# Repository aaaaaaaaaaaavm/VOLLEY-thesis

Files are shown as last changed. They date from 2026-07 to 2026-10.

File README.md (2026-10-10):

# VOLLEY Gen5 — final-year thesis and review

### A controlled electromagnetic CubeSat deployer configuration, evaluated by computation

This repository is the **standalone academic record** for VOLLEY Gen5. For the 10 October review, start with [how to present the old numbers and known errors](university/final_review_2026_10_10/READ_THIS_FIRST.md), then download the [offline presentation and evidence pack](university/final_review_2026_10_10/TOMORROW_PRESENTATION_PACK.zip). The repository holds the technical [manuscript](source/VOLLEY_IEEE_Conference.pdf), editable [source](source/paper.tex), model scripts and outputs, CAD, validation sheets, assumptions, defects, and the college [final-review presentation pack](university/final_review_2026_10_10/README.md). A professor can follow a slide claim to a result file and method without opening another repository.

> **Scope, October 2026:** Gen5 is the fixed computational configuration for academic review, with documented model cases and open verification items. It yields a modeled orbital benefit, a failed installed-mass criterion, and a failed side-fed CAD fit. The final academic freeze has not been declared; nothing has been built, fired, measured, qualified or flown. Gen6 is the proposed first mission-derived instrumented prototype programme; 1 km/s-class release is separate long-range research. It has no selected architecture or achieved speed.

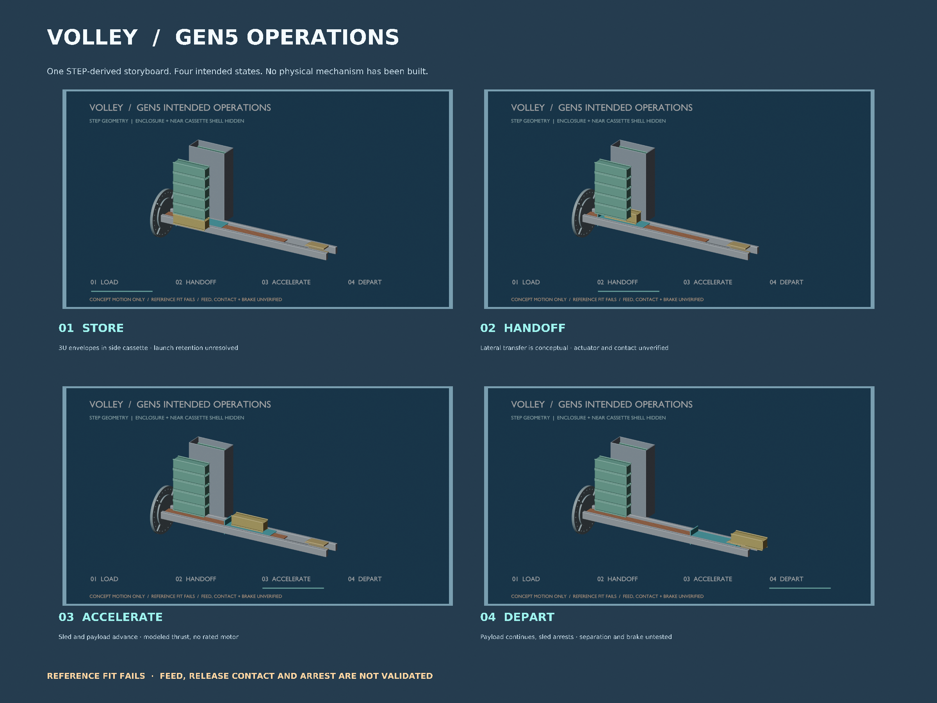
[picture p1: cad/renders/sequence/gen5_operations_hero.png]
Four-stage STEP-derived Blender storyboard of intended Gen5 storage, handoff, acceleration and departure


*The intended order of operations, shown with local FreeCAD-linked STEP solids. The enclosure and near cassette shell are hidden. The evaluated reference assembly has a known track/cassette clash; feed, contact and brake motion are unverified. [Watch the eight-second sequence](cad/renders/sequence/gen5_intended_sequence.mp4) · [view animation provenance](cad/renders/sequence/README.md) · [inspect the static geometry audit](cad/renders/step_review/README.md). This is a model visualization, not hardware.*

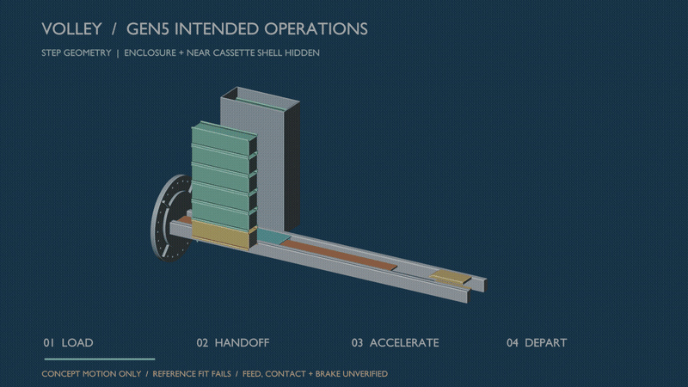
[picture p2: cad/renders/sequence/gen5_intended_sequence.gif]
Gen5 intended-operations concept animation, not a tested mechanism


> **Finding for the examiner:** the finite 3-D analytic force screen gives **12.448 m/s under ideal phase**, challenging the earlier **16.029 m/s** periodic-model shot. A separate 2-D FEM screen finds **1.082 kJ** ideal work. A conditional finite-force bank calculation gives **2.099 kJ** gross for the assumed full winding. None establishes a selected motor rating. [3-D analytic screen](validation/P118_gen5_finite_force_map.md) · [2-D FEM](validation/P119_gen5_finite_force_fem2d.md) · [coupled bank case](validation/P120_gen5_finite_coupled_shot.md) · [affected-claim disposition](docs/GEN5_2026_10_09_FINDING_DISPOSITION.md).

> **New cross-check and sensitivity:** an [independent depth-resolved 3-D surface-charge formulation](validation/P121_gen5_finite_force_surface3d.md) returns **1.042 kJ ideal work**, agreeing with the analytic finite-force screen under shared geometry and material assumptions. [Illustrative geometry cases](validation/P122_gen5_finite_force_sensitivity.md) reduce ideal work to **0.907 kJ at a 14 mm face gap** versus 12 mm nominal. These are computational screens, not measured tolerances or an accepted speed rating.

> **Updated finding for the examiner, 10 October 2026:** [P123](validation/P123_gen5_one_event_mass_screen.md) calculates a one-release installed-mass trade with the same assumed host and payload. The ideal finite-force Gen5 case saves **1.866 kg** of fuel if both options carry 10 kg, but its modeled device is **54.562 kg** heavier. With fuel hypothetically resized for only one event, Gen5 remains **52.717 kg** heavier on the device-plus-fuel proxy. Achieving parity at this ideal speed requires about **52.630 kg** less device dry mass. [Code](analysis/gen5_one_event_mass_screen.py) · [result JSON](analysis/results/gen5_one_event_mass_screen.json). This does not close a twelve-shot mission or validate a motor. The manuscript, report and review deck now include the limited P123 result and the later P125 source-power failure, P126 assumed R1 tolerance and P127 arrest bound.

> **Additional viva bound:** even if an ideal release removed the host preburn entirely, the same one-event comparison allows at most **74.659 kg** of Gen5 device against the current 126.562 kg model. [Recompute it locally](analysis/gen5_architecture_bounds.py) · [read the unselected H1 hypothesis](docs/GEN5_H1_INTEGRATED_DEPLOYER_HYPOTHESIS.md). The manuscript and report include the bound; H1 remains unselected.

> **New examiner requirements screen, P124:** [orbit and stroke calculations](validation/P124_precision_delivery_design_space.md) show how a declared 450 km orbital-state tolerance becomes an ideal tangential velocity margin. They also give about **39,220 g** for 1 km/s over Gen5's 1.3 m stroke with a 4 kg payload. This is a kinematic screen, not a motor rating or qualified load. The report, manuscript and slide 23 now include the result. [Code](analysis/precision_delivery_design_space.py) · [result](analysis/results/precision_delivery_design_space.json).

The [P127 release/arrest bounds](validation/P127_gen5_release_arrest_bounds.md) find 731.8 J of sled kinetic energy at the **ideal** finite-force speed. Over the provisional 210 mm brake corridor, stopping it needs at least 37.6 g mean sled deceleration; the first-order host reaction and net recoil are also bounded. Eddy-current peak force, payload contact, host attitude and repeated-shot thermal behavior remain unsolved.

> **P125 drive feasibility screen:** A quasi-steady, three-phase voltage/current model uses the finite Gen5 force map and the historical **unselected** winding and 96 V source. The reference surrogate reaches 12.448 m/s; halving the current limit gives 8.802 m/s and halving the initial source voltage gives 10.794 m/s. A single string at the older 116–185 mΩ commercial ESR bound **fails the source-power equation before release**; ideal parallel-string branches complete while multiplying source cells and mass. These are conditional model outputs, **not a rated release speed or selected drive**. [Method and limits](validation/P125_gen5_voltage_limited_screen.md) · [source](analysis/gen5_voltage_limited_screen.py) · [result](analysis/results/gen5_voltage_limited_screen.json).

The [prototype-to-flight decision gates](docs/GEN6_PROTOTYPE_TO_FLIGHT_ROADMAP.md) make the proposed Gen6 first article and later engineering, qualification and flight stages reviewable. None is an achieved Gen6 milestone.

Ideal speed, stroke and payload-load screen

P123 one-event installed device and fuel comparison

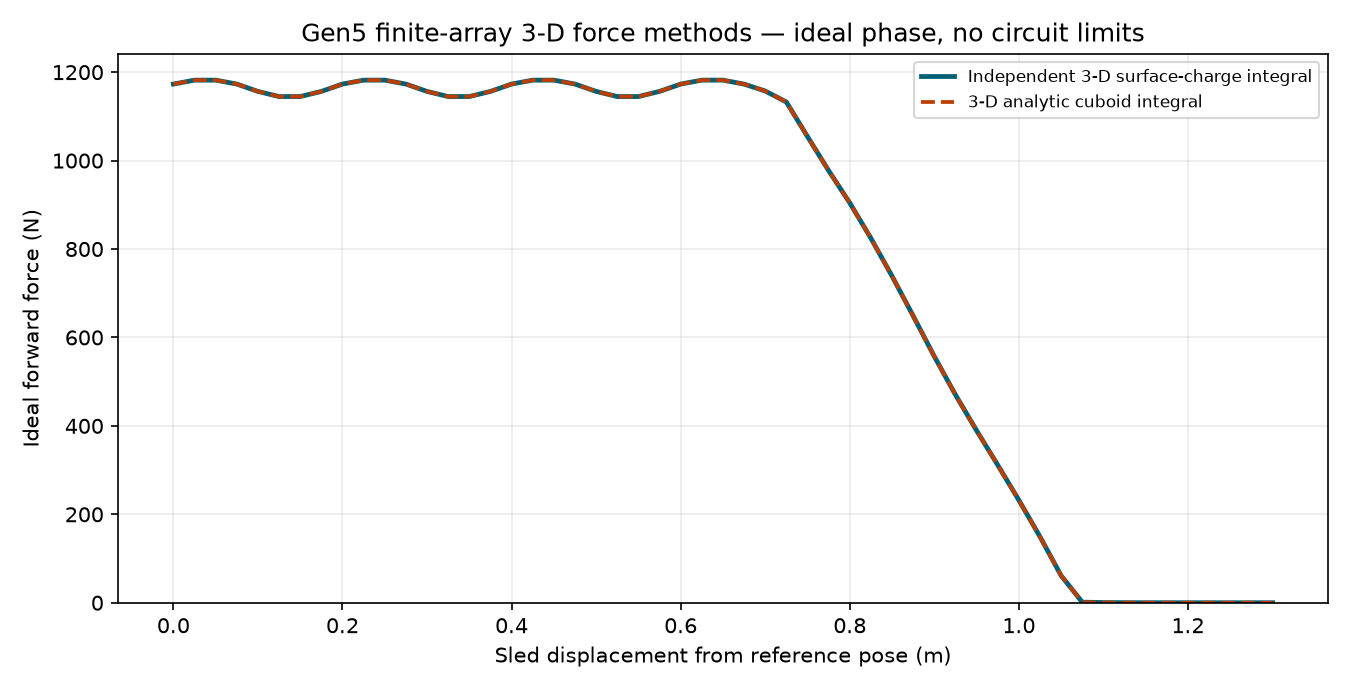
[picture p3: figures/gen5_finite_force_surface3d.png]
Independent depth-resolved ideal-force check
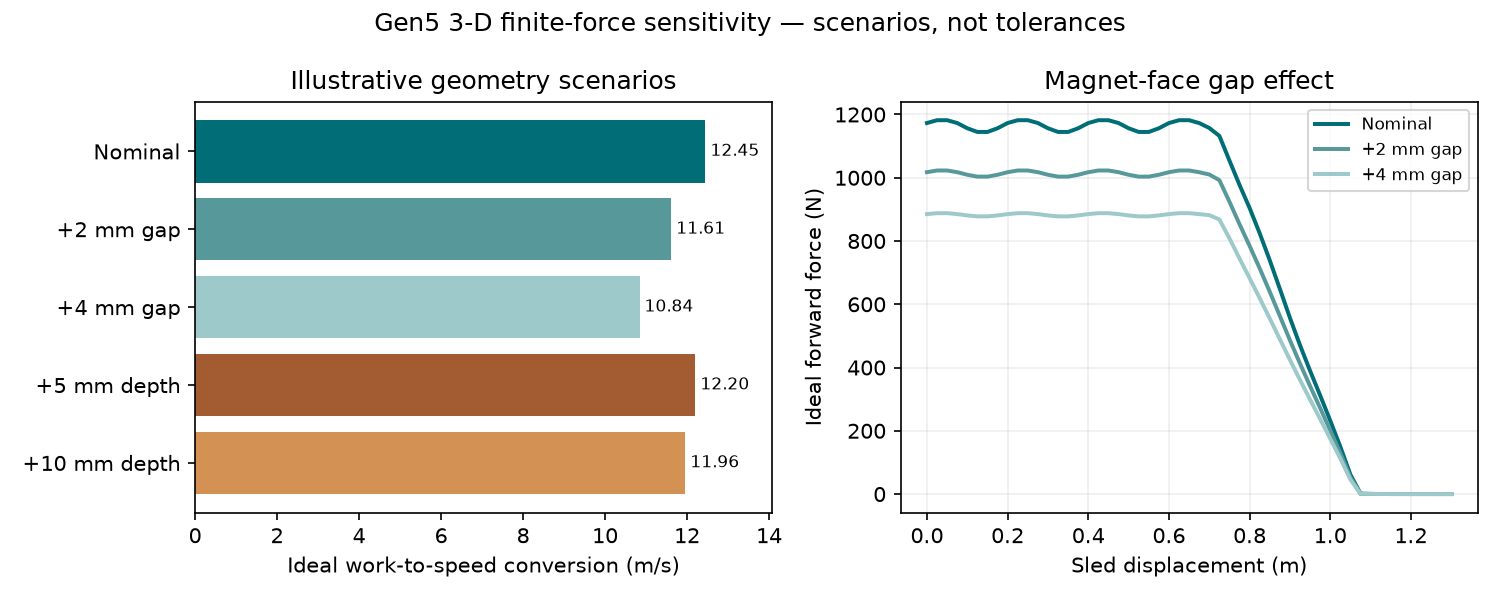
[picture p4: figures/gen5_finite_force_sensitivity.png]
Deterministic magnet gap and depth scenarios


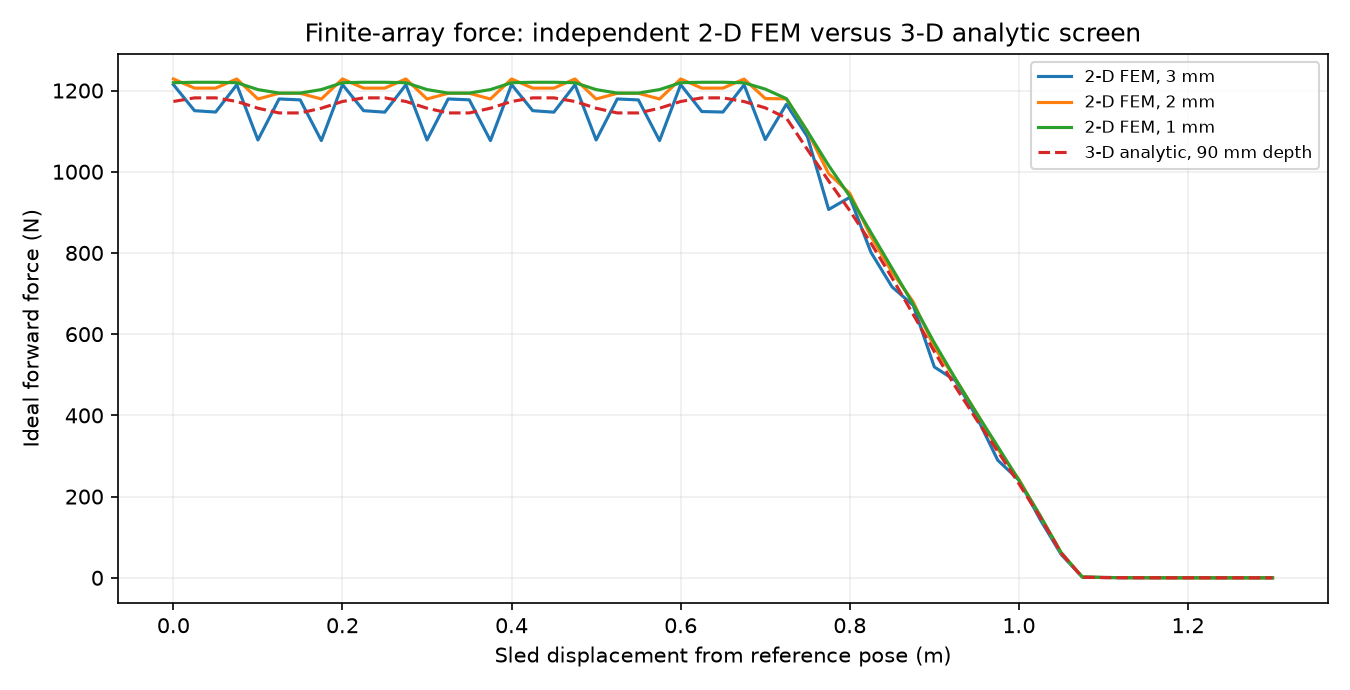
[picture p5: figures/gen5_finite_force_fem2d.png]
Finite 2-D FEM force comparison
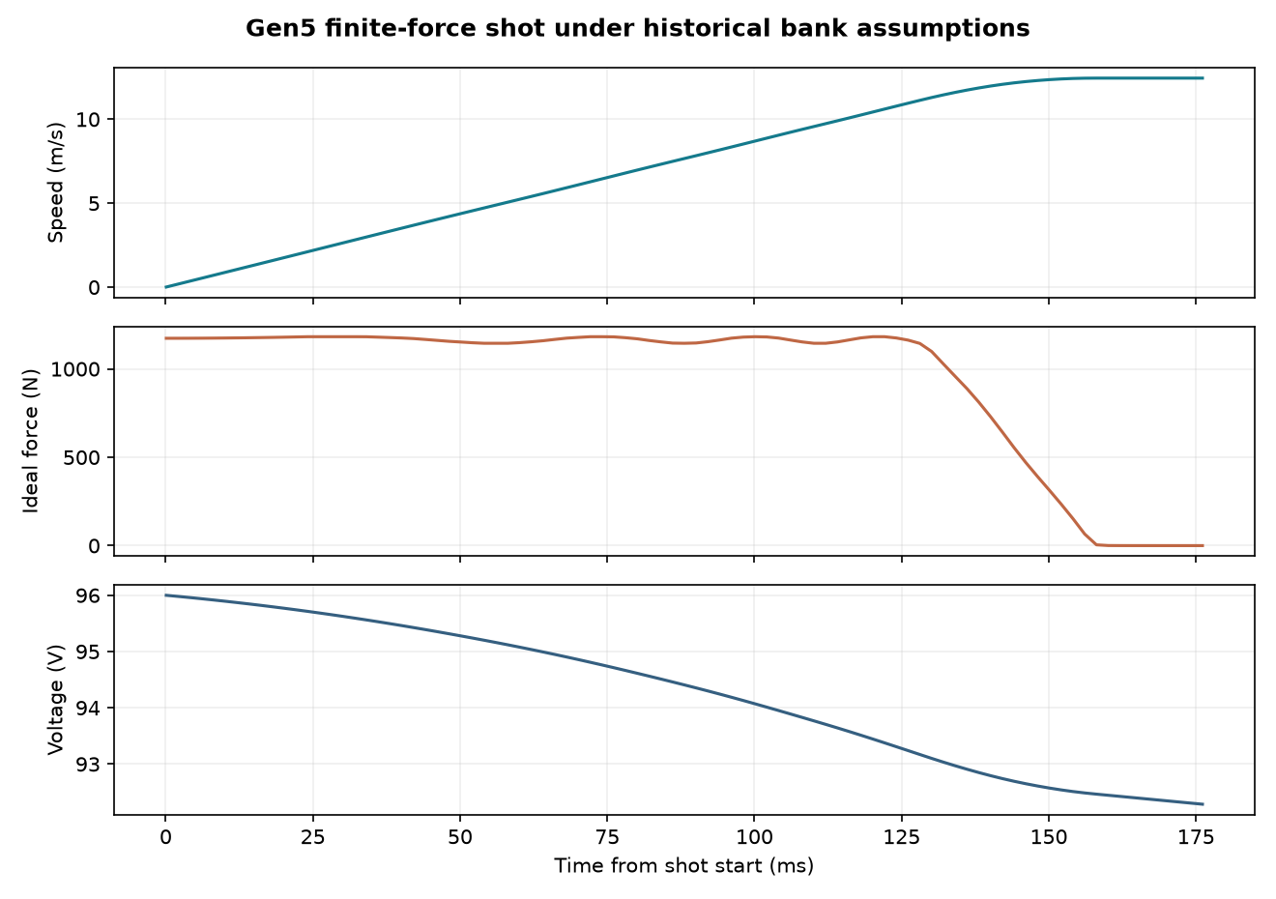
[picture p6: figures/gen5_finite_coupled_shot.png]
Assumed finite-force bank trajectories


*The FEM omits magnet-depth end effects and the coupled shot retains assumed bank, converter and ideal phase. The [matched reference](docs/MATCHED_MISSION_REFERENCE.md) uses assumed host and dispenser properties; none of its spring or Gen5 twelve-shot cases closes.*

<p align="center">VOLLEY mission concept and Gen5 model chain</p>

*Model and mission architecture. A host and provider interface have not been selected.*

## Bring this to the final review

| Deliverable | Open it | Evidence route |
|:--|:--|:--|
| **26-slide college presentation** | [PDF](university/final_review_2026_10_10/VOLLEY_Final_Review_2026-10-10.pdf) · [editable PPTX](university/final_review_2026_10_10/VOLLEY_Final_Review_2026-10-10.pptx) | [Slide-by-slide claim map](university/final_review_2026_10_10/CLAIM_EVIDENCE_MAP.md) |
| **Panel handbook** | [PDF](university/final_review_2026_10_10/PANEL_HANDBOOK.pdf) · [Markdown](university/final_review_2026_10_10/PANEL_HANDBOOK.md) | Detailed explanations and figures |
| **Presenter reference** | [PDF](university/final_review_2026_10_10/PRESENTER_REFERENCE.pdf) · [Markdown](university/final_review_2026_10_10/PRESENTER_REFERENCE.md) | Slide notes and viva responses |
| **Final-year project report** | [PDF](university/GEN5_FINAL_YEAR_REPORT.pdf) · [Markdown](university/GEN5_FINAL_YEAR_REPORT.md) | Chaptered academic review draft; college-specific format remains to be applied |
| **Technical manuscript** | [PDF](source/VOLLEY_IEEE_Conference.pdf) · [LaTeX](source/paper.tex) | [Local evidence guide](ACADEMIC_EVIDENCE.md) |
| **Engineering review reports** | [Computational PDF](reports/GEN5_COMPUTATIONAL_REVIEW.pdf) · [FreeCAD/CAD PDF](cad/GEN5_CAD_REVIEW.pdf) | [Orbit check](validation/P115_rated_orbit_cartesian.md) · [Assembly check](validation/P116_gen5_assembly_packaging.md) |

The presentation pack credits **Adityavardhan Mishra and Pratham Chawla**, with guide **Vikas Gulia**. The existing technical manuscript names Adityavardhan Mishra; the review pack does not retroactively change its authorship. [Remaining CAD and IEEE work](IEEE_AND_CAD_REMAINING_WORK.md) · [IEEE prior-art update](IEEE_PRIOR_ART_UPDATE_2026-10-09.md) · [Manuscript claim audit](CLAIM_CORRECTIONS_2026-10-09.md) · [Pack instructions](university/final_review_2026_10_10/README.md) · [Review-pack checksums](university/final_review_2026_10_10/CHECKSUMS.sha256) · [Academic artifact checksums](ARTIFACT_MANIFEST.sha256).

To rebuild the chaptered report from this repository, run `pandoc university/GEN5_FINAL_YEAR_REPORT.md -o university/GEN5_FINAL_YEAR_REPORT.pdf --pdf-engine=xelatex --resource-path=university`. Its source includes the page format and font settings. The college supplied a final-review rubric and example slides, but no mandatory report template; the PDF is an academic review draft awaiting that format and final authorship confirmation.

**Market context for the viva:** [audited customer and spacecraft fit](MARKET_AND_CUSTOMER_FIT.md). It checks the relevant Drive market report and independent business-case review against primary industry sources and the Gen5 result. Candidate buyers and satellite classes are hypotheses, not endorsed customers or qualified payloads.

## The result to defend

Gen5 is one specified system: a release station 1.5 m from the breech on 1.8 m structural longerons, with a 1.3 m powered stroke, ironless double-sided Halbach linear motor, reusable permanent-magnet sled, pulse store, eddy-current arrest and two conceptual cassettes for twelve ordinary 3U CubeSats. The release load and mechanical/electrical compatibility of any actual CubeSat remain unqualified.

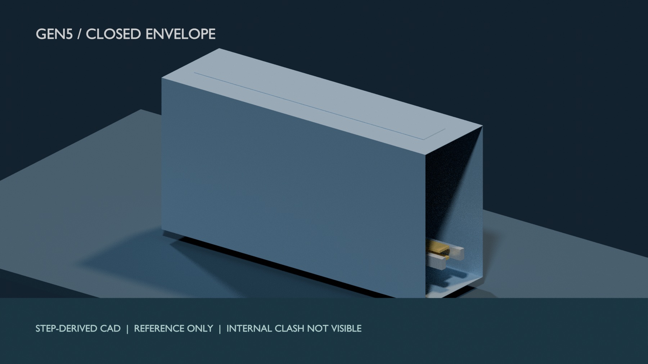
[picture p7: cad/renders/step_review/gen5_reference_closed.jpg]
Gen5 outer reference envelope from STEP; internal clash concealed
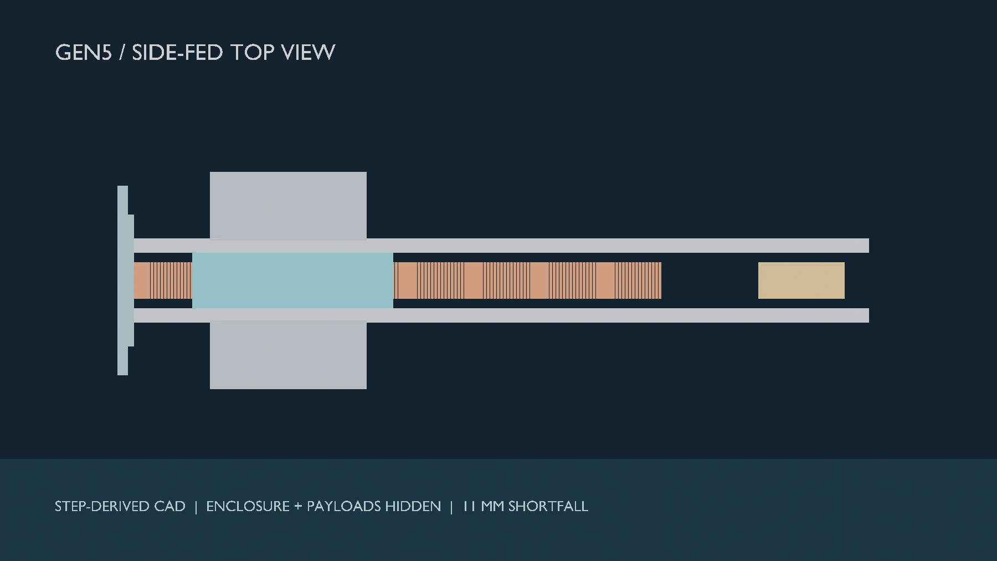
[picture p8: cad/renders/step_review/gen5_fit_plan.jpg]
Gen5 reference side-fed track and cassettes from STEP; enclosure and payloads hidden


*Gen5 CAD models. These depict the evaluated geometry; they are not built articles or manufacturing drawings. [Inspect local CAD](cad/).*

| Study question | Modeled Gen5 answer | Examiner's qualification |
|:--|--:|:--|
| Historical rated 3U departure | **16.029 m/s at 10.07 g** | Periodic model challenged by finite geometry; not a measured command range or payload qualification |
| Energy draw | **2.78 kJ gross per shot** | Circuit model at the rated point |
| Exit-speed dispersion | **0.0274 m/s (3σ)** | Simulation under assumed sensor uncertainty |
| Dry / loaded design mass | **126.6 / 174.6 kg** | Modeled rollup with historical Gen3 sled volumes and assumed components, not a complete installed host mass |
| Mass per carried 3U | **10.547 kg** | **Fails** the approximately 2 kg/satellite economic screen |
| Incumbent canister parity | **1.758×** a roughly 6 kg/3U canister | **Fails** the separate ±15% parity band |
| One modeled 450 km orbit case | **28.8 km** semi-major-axis rise; **1.60×** lifetime | Conditional atmosphere and orbit assumptions; current lifetime point lacks an independent rerun |
| Current rated two-body cross-check | **28.800775 km** immediate axis rise | Independent Cartesian propagation; lifetime, host and delivery excluded |
| Side-fed reference assembly fit | **11 mm shortfall** | FreeCAD and CadQuery exact solids collide by 32,915 mm³ per cassette |

[Frozen numerical baseline](appendix/BASELINE.md) · [Claim provenance](appendix/PROVENANCE.md) · [Study limits and viva questions](ACADEMIC_EVIDENCE.md) · [Defect register](appendix/OPEN_PROBLEMS.md)

<p align="center">Gen5 mass per 3U against the canister and economic screens Historical periodic-model shot energy accounting</p>

*These review charts are generated by the local [plot script](tools/plot_gen5_decision.py) from [mass](analysis/results/mass_properties.json) and historical [shot](analysis/results/motor_results.json) outputs. The canister value is approximate; [P117](validation/P117_rated_energy_mass_audit.md) reconciles the old 124.488 J compact-output remainder to model assumptions. This does not verify installed power hardware.*

<p align="center">Rated two-body orbit check Gen5 reference assembly interference</p>

*The CAD finding is deliberately retained in the [native FreeCAD document](cad/native/Gen5_Review.FCStd) and [assembly STEP](cad/step/gen5/VOLLEY_Review_Assembly_FreeCAD_Gen5.step). The orbit check supports immediate two-body geometry only. [Methods and exact files](reports/GEN5_COMPUTATIONAL_REVIEW.pdf).*

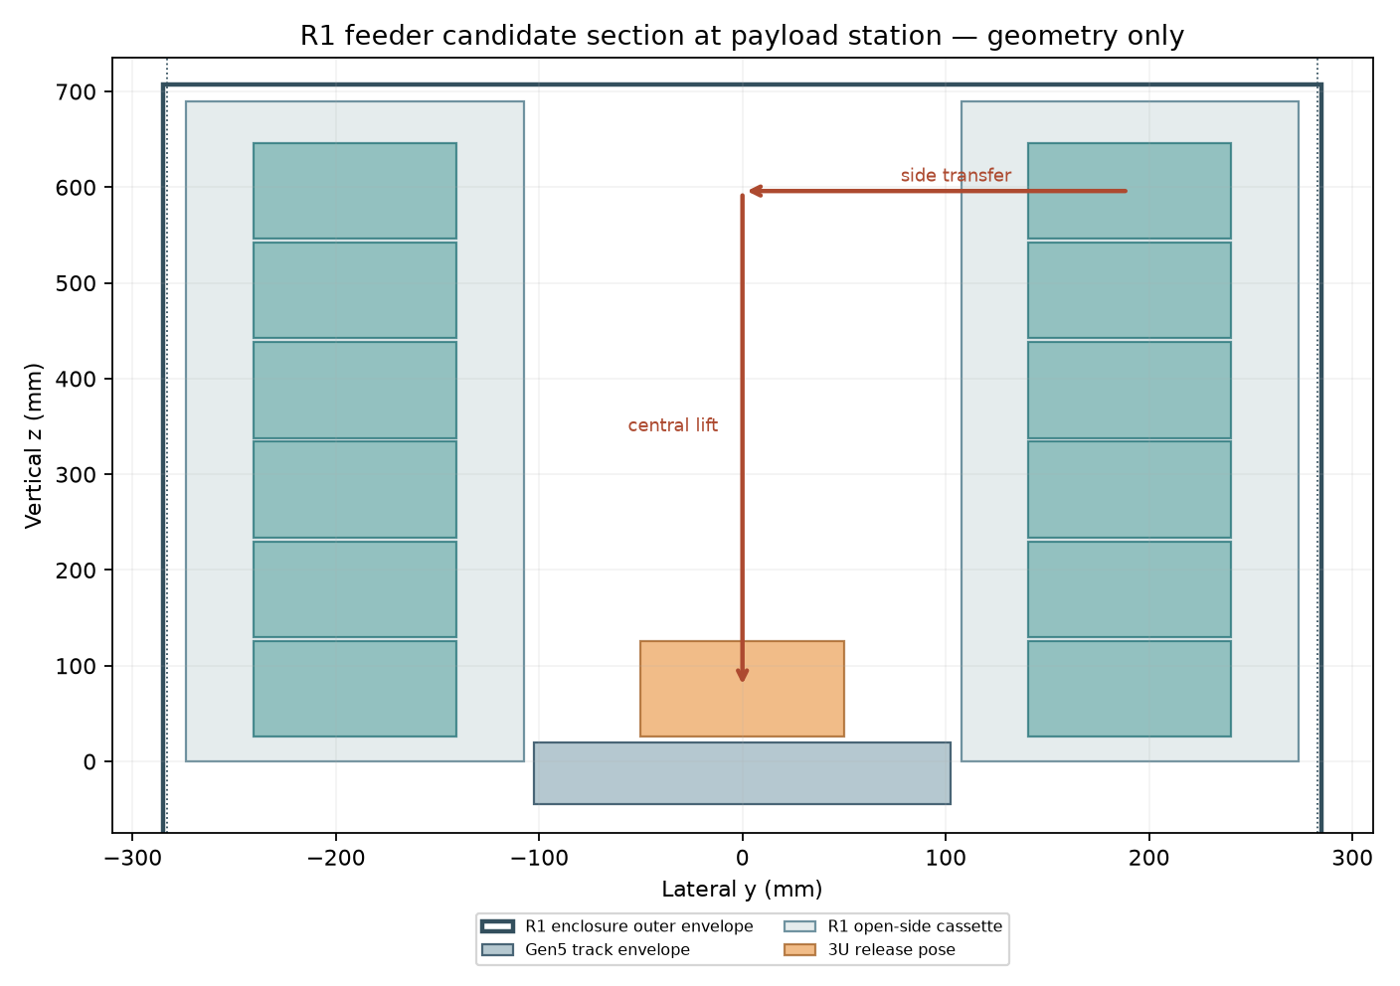
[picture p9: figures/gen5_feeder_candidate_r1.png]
Unselected R1 feeder geometry


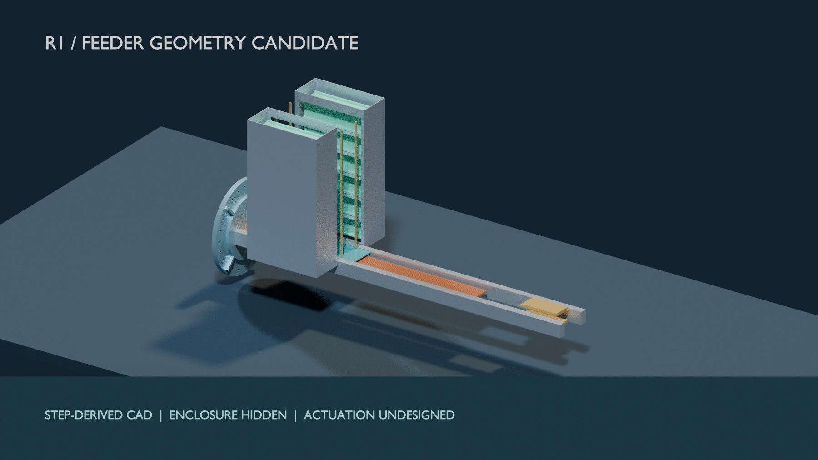
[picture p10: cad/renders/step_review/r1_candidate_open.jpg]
STEP-derived widened R1 candidate with its enclosure hidden


The [P126 R1 tolerance screen](cad/FEEDER_R1_TOLERANCE_SCREEN.md) finds 1.31 mm residual for an assumed 0.2° alignment band and −0.47 mm for 0.5° against the R1 CAD-derived 5 mm nominal side gap. These bands are illustrative; moving hardware and flight tolerances remain unselected.

*The [R1 FreeCAD and STEP geometry study](cad/FEEDER_CANDIDATE_R1.md) widens the enclosure and clears twelve scripted 3U envelope paths. Lift actuation, launch retention, tolerances, mass revision and provider compatibility remain open; R1 is not a selected Gen5 configuration.*

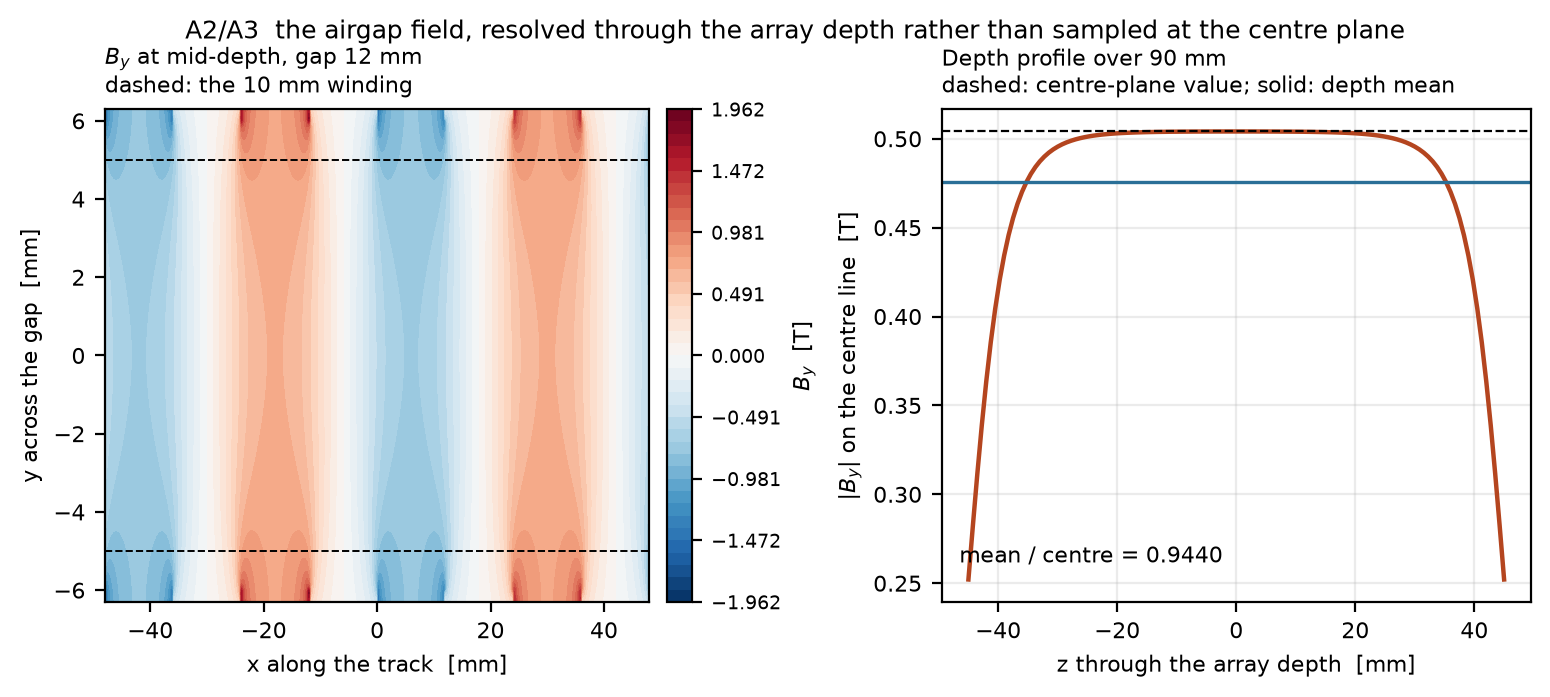
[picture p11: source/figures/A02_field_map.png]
Calculated magnetic field
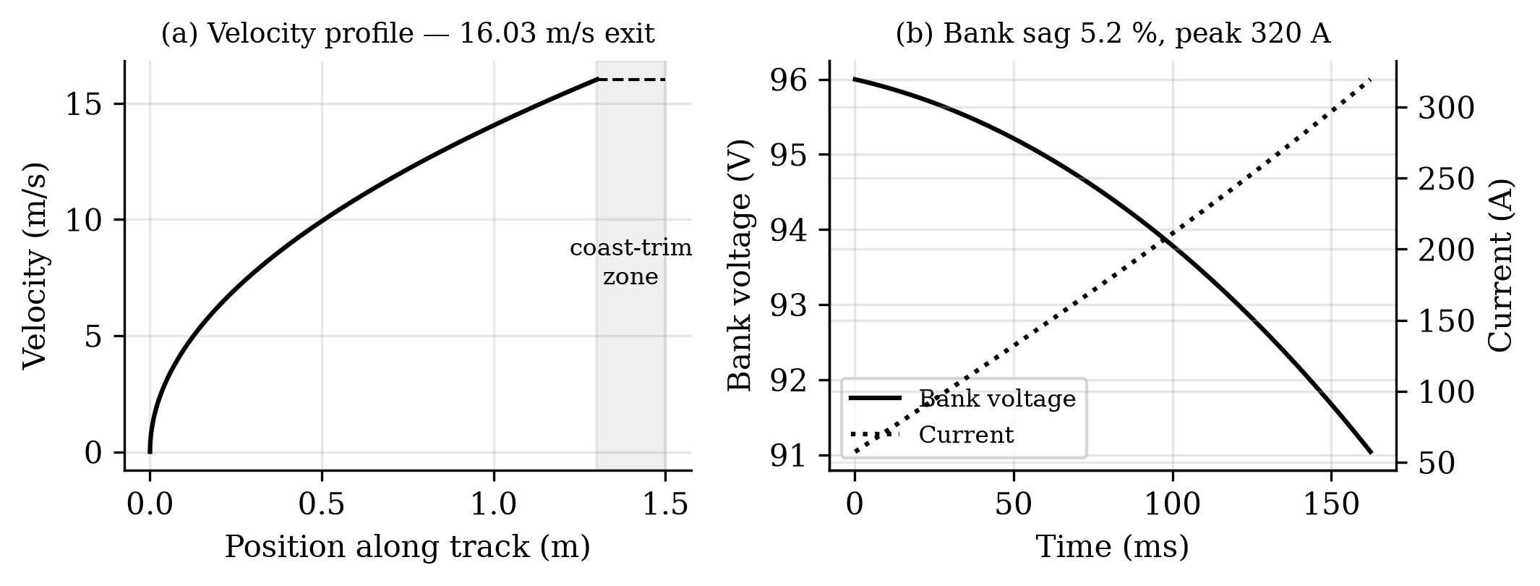
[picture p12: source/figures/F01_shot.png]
Modeled velocity, force and current
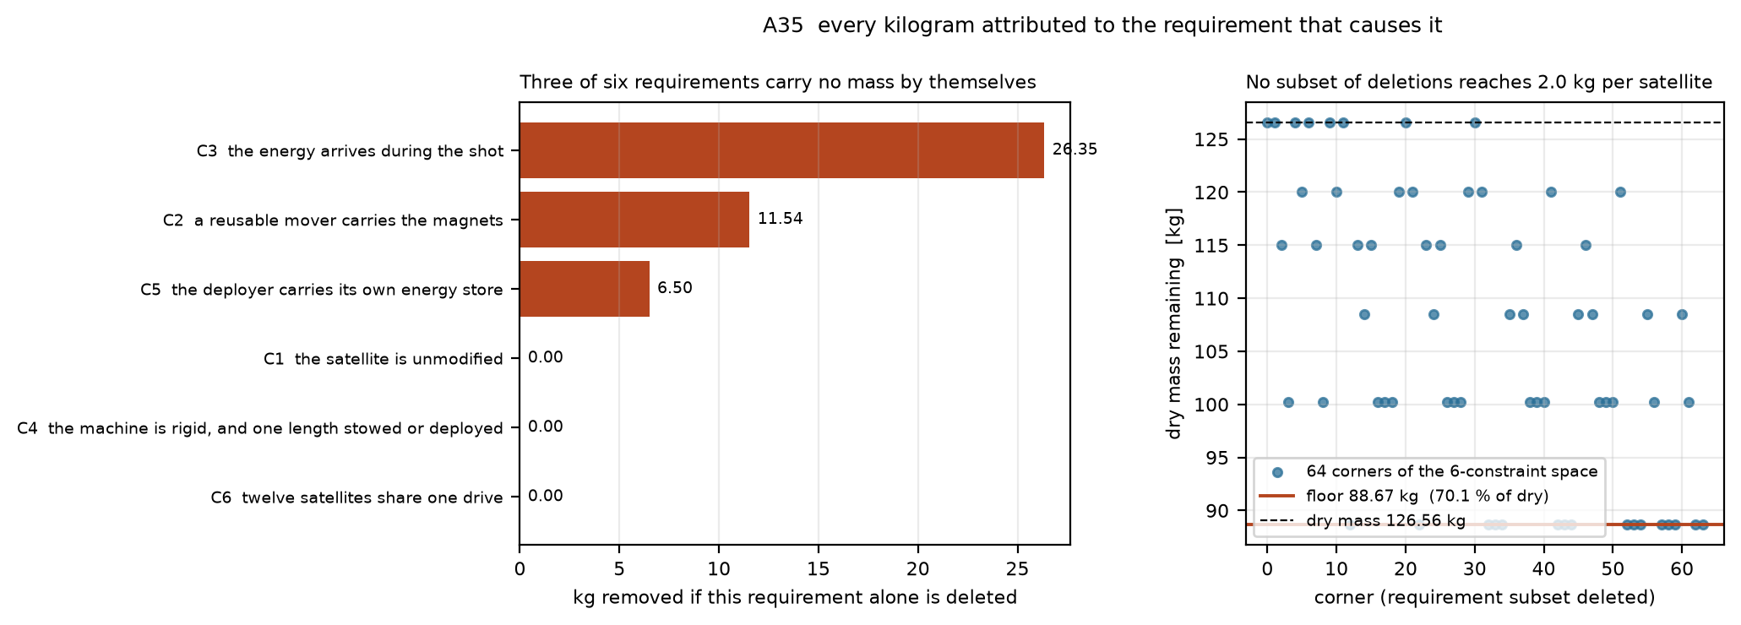
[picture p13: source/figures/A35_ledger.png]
Requirement-attributed mass floor


*Field → shot → mass decision. Independent numerical methods check specific model quantities; none is an experimental Gen5 validation.*

## Method and traceability

| Evidence layer | What is here | What it does not establish |
|:--|:--|:--|
| [Analysis](analysis/) | Executable electromagnetic, shot, mass and orbit models with captured result JSON | Correctness of unknown material, sensor or host inputs |
| [Validation](validation/) | Predeclared acceptance bands, numerical solver cross-checks, failed bands | Hardware repeatability or flight qualification |
| [CAD](cad/) | Gen5 geometry, STEP parts and mass properties | Fabrication readiness, fit to an approved host or full tolerance stack |
| [Appendix](appendix/) | Baseline, prior art, literature, provenance, decisions, defects | External endorsement |
| [Final-review claim map](university/final_review_2026_10_10/CLAIM_EVIDENCE_MAP.md) | Each slide's local evidence and caveat | Replacement for the underlying run sheet |

The analysis and reference files began as a dated engineering snapshot and now include local P115/P116 checks and FreeCAD exports. The manuscript, review pack and this examiner-facing guide are authored here. The local files define the academic claims; a later change in another repository does not silently alter them.

Run `python3 tools/check_review_surface.py` for a fast, dependency-light check of the current academic route: local links, manuscript figures, captured-result identities, artifact hashes and PDF/ZIP integrity. Historical copied validation and appendix records retain some links to a wider programme archive; the presentation's current numerical claims use the local sources in the claim map.

## The academic boundary

The result is a **documented computational study with a negative selection screen for the evaluated 3U configuration**. Integrated thrust, the coupled shot chain, and other engineering closures remain open. The lack of a physical prototype is stated directly; published tests of other devices support context or parameters, not claims that VOLLEY itself was tested. The college rubric includes objectives, technical quality, results/validation, documentation, and presentation/viva. The supplied example deck gives a visual and section outline; it does not supply technical evidence for VOLLEY. [Review-pack rubric mapping](university/final_review_2026_10_10/README.md).

The manuscript uses an IEEE conference layout. A university-specific full-thesis template has not been supplied, and no claim is made that this PDF satisfies an unprovided submission format. The review presentation and academic evidence record are ready for scrutiny of their stated computational scope.

**Beyond Gen5:** [Gen6 direction](university/final_review_2026_10_10/GEN6_DIRECTION.md) frames 1 km/s as a research objective. A named host and ICD, complete installed-system model, payload-specific structural and release testing, repeated shots and full mission closure are future gates. [VOLLEY engineering](https://github.com/aaaaaaaaaaaavm/VOLLEY) and [paper companion](https://github.com/aaaaaaaaaaaavm/VOLLEY-paper) offer optional context; this repository contains the evidence needed to review this thesis.

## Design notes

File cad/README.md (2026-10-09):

# Gen5 CAD handover — current review configuration

This repository contains the Gen5 geometry needed to review its manuscript without opening another project. The **eight current source STEP parts** are generated by [`build_gen5.py`](build_gen5.py) from [`parameters.json`](parameters.json). The **eight FreeCAD 1.0 STEP exports** and [native `.FCStd` assembly](native/Gen5_Review.FCStd) are in this repository too. The [FreeCAD assembly STEP](step/gen5/VOLLEY_Review_Assembly_FreeCAD_Gen5.step) has 20 named instances: six fixed machine parts, two cassettes and twelve 3U envelope proxies. The imported B-reps do not have native FreeCAD feature histories.

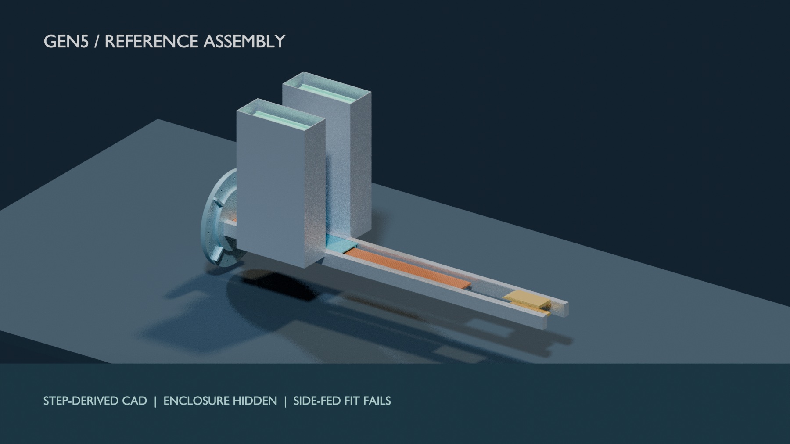
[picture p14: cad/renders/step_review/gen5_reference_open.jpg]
STEP-derived Gen5 reference assembly, enclosure hidden


*FreeCAD-linked STEP solids visualized in Blender; the evaluated side-fed placement has a known clash. [Six labeled JPEGs, exact source hashes and rebuild commands](renders/step_review/README.md). No built hardware or GUI solver screenshot.*

**Review decision:** the side-fed reference placement **fails**. Two 166 mm cassettes and the 205 mm track require 537 mm across a 526 mm internal enclosure width before clearance. CadQuery and FreeCAD exact-solid intersections both find 32,915 mm³ of track/cassette overlap per side. Inspect the [three-page CAD review PDF](GEN5_CAD_REVIEW.pdf), [source report](GEN5_CAD_REVIEW.md), [reference assembly JSON](REVIEW_ASSEMBLY.json), [FreeCAD read-back JSON](FREECAD_EXPORT.json), and [P116 run sheet](../validation/P116_gen5_assembly_packaging.md).

| Local file group | Purpose |
|:--|:--|
| [Source STEP parts](step/gen5/) | Current Gen5 shape inputs and two reference assembly exports |
| [FreeCAD STEP parts](step/freecad_gen5/) | Independent STEP export and validity/volume read-back of all eight source parts |
| [FreeCAD native document](native/Gen5_Review.FCStd) | Named component tree and stated review placements |
| [Dimensions](DIMENSIONS.md), [BOM](BOM.md) | Geometric parameters and modeled mass ledger |
| [STEP review images](renders/step_review/README.md) | Open, closed, top and drive-detail Gen5 views plus separate unselected R1 views |
| [Build scripts](build_review_assembly.py), [FreeCAD export](freecad_export_review.py) | Reproduce the reference handover |

The 126.6 kg modeled dry rollup is **not** a FreeCAD assembly weight. Its 9.445 kg sled uses historical Gen3 solid volumes, and other components are modeled or assumed. The host flange is a reference shape, not a provider-approved ICD; feeder motion, retention, fasteners, harness, tolerances, payload qualification and host integration remain open. Gen3 files, where included for traceability, are historical mass/FEA inputs, not the current geometry.

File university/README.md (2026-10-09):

# University-specific material

**This directory is never touched by `export_companion.py`.** Submission forms, templates, formatting mandates and viva material go here.

Everything outside this directory is generated and will be overwritten on the next export.

## Final project review, 10 October 2026

The [final-review pack](final_review_2026_10_10/README.md) contains the university-format presentation, the detailed panel handbook, the presenter reference book, and a claim-to-evidence map. It credits both presenters and distinguishes the analysed Gen5 thesis baseline from the open Gen6 direction.

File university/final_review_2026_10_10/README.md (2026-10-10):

# Final B.Tech project review — 10 October 2026

**Presenters:** Adityavardhan Mishra (PRN 23070125054) and Pratham Chawla (PRN 23070125029)<br>
**Guide:** Vikas Gulia<br>
**Institution:** Symbiosis Institute of Technology, Pune

This directory is the review pack for the computational Gen5 study. It follows the user's eleven-part outline and the visual format of the supplied university example PDF: SIT cover and logo, cyan content headings, white body, and numbered slides. The example PDF contained another project's work; none of that work was reused as VOLLEY content.

**Presentation thesis:** the Gen5 system-level computational evaluation reports a conditional orbital benefit, a failed 3U mass criterion, and a failed side-fed CAD reference fit. Slides 1–22 present the research and its limitations. Slides 23–24 label Gen6 as future work, with no achieved Gen6 speed or selected mechanism. Completion here means an answered analytical question, not a qualified flight product or final design freeze.

## Bring to the review

**Start with [How to present the old numbers and known errors](READ_THIS_FIRST.md)** and give the panel the [one-page evidence handout](PANEL_HANDOUT.pdf). The [15-minute two-speaker run sheet](TOMORROW_RUN_SHEET.pdf) assigns the handoff, timing and fallback route. The deck places the historical shot beside the 3-D analytic force screen, independent 2-D FEM, and conditional bank rerun; slide 20 shows the computational force-to-mission chain. An offline presentation and core-evidence ZIP is provided as `TOMORROW_PRESENTATION_PACK.zip`; the reproducible source remains in this repository.

| Item | Present/print | Editable source |
|:--|:--|:--|
| Main presentation, 26 slides | [PPTX](VOLLEY_Final_Review_2026-10-10.pptx) · [PDF](VOLLEY_Final_Review_2026-10-10.pdf) | [Build script](build_presentation.py) |
| Panel handbook, detailed explanation and figures | [PDF](PANEL_HANDBOOK.pdf) | [Markdown](PANEL_HANDBOOK.md) · [DOCX](PANEL_HANDBOOK.docx) |
| Presenter reference, slide notes and viva answers | [PDF](PRESENTER_REFERENCE.pdf) | [Markdown](PRESENTER_REFERENCE.md) · [DOCX](PRESENTER_REFERENCE.docx) |

The [claim and evidence map](CLAIM_EVIDENCE_MAP.md) traces every substantive slide to the manuscript, numerical result and/or project-plan source. The [Gen6 direction](GEN6_DIRECTION.md) records precisely what the forward-looking slides mean. The full technical detail remains in the [manuscript PDF](../../source/VOLLEY_IEEE_Conference.pdf), [computational report](../../reports/GEN5_COMPUTATIONAL_REVIEW.pdf), [FreeCAD review report](../../cad/GEN5_CAD_REVIEW.pdf), [`analysis/`](../../analysis/), [`validation/`](../../validation/), [`cad/`](../../cad/) and [`appendix/`](../../appendix/). The reports include simulation plots and software-generated CAD views; none represents a physical test.

The deck's assembly images are [STEP-derived, Blender-rendered review views](../../cad/renders/step_review/README.md). The source STEP and FreeCAD files, image hashes, visible parts and hidden enclosure are recorded in the [view provenance](../../cad/renders/step_review/PROVENANCE.json). The offline ZIP includes all six JPEGs alongside the deck. It also includes an optional [four-stage operations storyboard](../../cad/renders/sequence/gen5_operations_hero.png), [eight-second video](../../cad/renders/sequence/gen5_intended_sequence.mp4) and [P124 ideal load figure](../../figures/precision_delivery_design_space.png) under `VISUALS/`. The video is a **conceptual motion aid**; it does not validate feed, contact, clearance or braking. The exact-solid width and interference findings come from the CAD audit.

Slide 3 and the handbook introduce the [audited market and spacecraft-fit report](../../MARKET_AND_CUSTOMER_FIT.md). They identify candidate buyer jobs without claiming customer interviews, qualified spacecraft or product-market fit. The source-linked report corrects the Drive material before it enters the review narrative.

**Review corrections:** an earlier draft said release timing alone could create persistent in-track phase. That was wrong for zero-relative-impulse releases from an unchanged co-orbital host. A separate historical-input two-body run now checks the immediate 28.800775 km axis change, but not the 1.60× atmospheric lifetime. A native FreeCAD assembly review identifies the 11 mm side-fed width shortfall. The current PPTX, PDF, handbook and presenter notes include those findings, the P123 one-event device-plus-fuel penalty, P124's ideal stroke/load requirement screen, P125's single-string bank failure, P126's illustrative R1 tolerance failure, and P127's necessary arrest load. Neither screen demonstrates product value or hardware performance.

## Evidence language

- The captured Gen5 computational cases and their negative 3U selection decision are documented. Results are predictions; numerical cross-checks apply to named models and cases. No VOLLEY hardware has been built or physically tested.
- The modelled Gen5 3U system fails its preset mass-parity criterion against a spring canister. Its stated side-fed reference assembly also fails a width and exact-solid interference check. Both negative findings are in the presentation and handbook.
- Gen6 is an **open architecture trade**. Its approximately 1–2 m/s to 1 km/s span is an investigation envelope. No 1 km/s performance, mechanism selection, payload qualification, host compatibility or build/test release is claimed.
- The historical thesis manuscript is authored under Adityavardhan Mishra's name. This review pack credits both named presenters; it does not retroactively change manuscript authorship.

## University final-review rubric coverage

| Criterion | Review evidence |
|:--|:--|
| Achievement of objectives (10 marks) | Slides 6, 11, 22; handbook §§4, 7–9 |
| Technical quality and innovation (10 marks) | Slides 4–8, 12–19; handbook §§2–5, 8 |
| Results, validation and analysis (5 marks) | Slides 13–21; handbook §8 and claim map |
| Report and documentation (5 marks) | Manuscript, baseline, validation, provenance and this pack |
| Presentation, demonstration and viva (10 marks) | Slide 20 computational demonstration; presenter reference |

## Rebuild

From this directory, run `python build_presentation.py` and `python render_review_pdf.py` to build the PPTX and matching 26-page PDF. The renderer checks text for overflow. The handbook and presenter PDFs and DOCXs can be rebuilt with Pandoc and XeLaTeX from their Markdown sources. All image references point to files already in this repository. The SIT logo in `assets/` was extracted from the user-provided university example PDF solely for this university-format review pack. Check [file hashes](CHECKSUMS.sha256) after copying the submission pack.

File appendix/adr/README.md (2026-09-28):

# Architecture Decision Records

Required by the Engineering Programme Dossier and the TRB prompt. One file per decision, in a
fixed shape, so a decision can be audited without reading a narrative.

[`../DECISION_LOG.md`](../DECISION_LOG.md) is not superseded. It is the readable history
and remains the better document for understanding *how the project got here*. These records are
the structured view: what was decided, what else was considered, what it costs, and how it gets
validated. Where an ADR has a Context section, that prose usually came from the decision log.

## Template

```
# ADR-NNN, title

Status · Date · Phase
## Context, the forces at play, including what was not known
## Decision, what was decided, stated flatly
## Alternatives, what else was considered, and why it lost
## Consequences, what this costs, including the bad parts
## Validation, how we would find out this was wrong
```

The Consequences and Validation sections are the ones that matter. A record listing only
benefits is advocacy, not a decision record, and one with no validation path violates dossier
§7, every feature needs a path toward validation.

## Index

| ADR | Decision | Status | Phase |
|---|---|---|---|
| [001](001-electromagnetic-deployment.md) | Electromagnetic deployment instead of a spring | Accepted | Concept |
| [002](002-host-is-a-spent-upper-stage.md) | Host is a spent upper stage, not a free-flyer | Accepted | Concept |
| [003](003-linear-synchronous-motor.md) | Linear synchronous motor, not a coilgun | Accepted | Load-bearing |
| [004](004-ironless-stator.md) | Ironless stator | Accepted | I |
| [005](005-eddy-brake-not-regeneration.md) | Eddy-current brake; sled energy is dissipated | Accepted | I |
| [006](006-magnets-ride-the-sled.md) | Magnets ride the sled; the CubeSat is unmodified | Accepted | Load-bearing |
| [007](007-dual-transverse-cassettes.md) | Dual transverse cassettes | Accepted | I |
| [008](008-retention-gate.md) | Retention gate separates preload from release | Accepted | I |
| [009](009-coast-and-trim.md) | Coast-and-trim release zone | Accepted | I |
| [010](010-host-agnostic-interface.md) | Host-agnostic four-item interface | Accepted | I |
| [011](011-publish-publicly.md) | Publish publicly, defects included | Accepted | I |
| [012](012-adopt-modelled-sled-mass.md) | Adopt the CAD-calculated 9.445 kg sled | Accepted | I |
| [013](013-drop-invariance-claim.md) | Drop the lifetime-ratio invariance claim | Accepted | I |
| [014](014-fleet-setpoint-below-ceiling.md) | Fleet setpoint at 98.2 % of the open-loop ceiling | Accepted | I |
| [015](015-derive-not-paste.md) | Derive coupled values; never paste them | Accepted | I |
| [016](016-reconstructed-history.md) | Reconstruct git history with labelled dates | Accepted | I |
| [017](017-four-repositories.md) | Four repositories, two of them generated | Accepted | I |
| [018](018-programme-name.md) | VOLLEY is the programme name; EMOCD_ remains the part prefix | Accepted | Programme |
| [019](019-gen4-open-assembly-before-export.md) | Keep Gen4 open assembly separate from the Phase I baseline | Accepted | Gen4 transition |
| [020](020-inter-shot-cadence.md) | The inter-shot cadence is 1200 s, closing P31 | Accepted | Load-bearing |
| [021](021-freeze-the-register.md) | Freeze the defect register; measurement takes priority | Accepted | I |
| [022](022-stator-segmented-not-block-commutated.md) | Winding segmented for fault isolation, driven as one; closes P29 | Accepted | I |
| [023](023-target-host-class.md) | Target host is a spent upper stage, not an ESPA-Grande port; closes P9 | Accepted | I |
| [024](024-last-mile-delivery-conops.md) | VOLLEY is a last-mile delivery vehicle; plane change excluded | Accepted | I |
| [025](025-fixed-cell-manifest.md) | One cell geometry with class-specific inserts, not a cassette per class | Accepted | I |
| [026](026-cad-built-from-parameters.md) | The CAD is generated from parameters, not drawn | Accepted | I |
| [027](027-designed-velocity-loop.md) | The velocity loop is designed against margins; closes P47 | Accepted | I |
| [028](028-no-latex-in-the-flagship.md) | No LaTeX in the flagship; the manuscript is authored in VOLLEY-paper | Accepted | I |
| [029](029-phase-one-closes-on-gen5.md) | Phase I closes on Gen5; historical study is the Phase II design target | Accepted | I |
| [030](030-apply-the-depth-resolved-thrust-constant.md) | Apply the depth-resolved K_t and the three decisions beside it; moves the baseline | Accepted | I |
| [031](031-four-repositories-not-two-phases.md) | Four repositories by role, replacing the two-phase model | Accepted |, |
| [032](032-legacy_study-stage-integrated-gas-store.md) | historical study is a stage-integrated, payload-direct, gas-driven deployer; supersedes the historical study of ADR-029 | Accepted |, |
| [033](033-legacy_study-trim-stage.md) | historical study gains a motor that steers rather than throws, adopted with its pulse store unweighed (P77) | Accepted | I |
| [034](034-legacy_study-long-stroke-design-point.md) | historical study's stroke becomes the host stage's whole 8.0 m, same velocity, half the acceleration, half the gas, and friction at 28.39 % of shot work (P78, P82, P83) | Accepted | I |
| [035](035-drive-tube-material.md) | The drive tube is hard-anodised aluminium and the piston matches it, closes P85, and forecloses steam | Accepted | I |
| [036](036-seal-specification-and-the-trim-stage.md) | The seal is specified at 17.8 N and the trim stage is suspended rather than built, closes P89, amends ADR-033, defers A66 | Accepted | I |
| [037](037-a66-band-one-was-unsatisfiable.md) | A66's first band was unsatisfiable by a correct implementation and is withdrawn rather than widened; band 1R replaces it | Accepted | I |

Every decision in `DECISION_LOG.md` appears above. ADRs 012-018 record decisions that were
never written down anywhere before.

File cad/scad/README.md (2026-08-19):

# The OpenSCAD model, and why there are two

`cad/build_gen5.py` builds Gen5 with **CadQuery**, a B-rep kernel, and exports STEP.
`gen5.scad` builds the same eight documents with **OpenSCAD**, a CSG kernel, and exports STL.

**Neither reads the other.** Both read `parameters.scad`, which is built from
`cad/parameters.json` by `cad/tools/make_scad_params.py` — OpenSCAD has no JSON parser, and a
second model that *pasted* its dimensions would be a second place for them to be wrong, which is
the opposite of what a cross-check is for. ADR-015: derive, never paste.

## Why it exists

Everywhere else this project checks a result by computing it a second way — the analytic Halbach
field against magpylib, both against a meshed FEM, orbit-averaged decay against Cowell RK4. **The
geometry never had that treatment.** `parameters.json` had been checked against exactly one model
built from it, and every guard in `tools/` compares a built artifact either against the
parameter file or against a rebuild of itself. Both agree by construction, because both descend
from the same script.

## What it found on the first run

**Two disagreements, and they were different kinds of thing.**

**One was a real defect in the CadQuery model — [P71](../../OPEN_PROBLEMS.md).** The sled rollers
were placed with a one-sided extrude and a half-width offset, as though the extrude were symmetric.
It is not. The +y roller sat at y 54–70 against a channel at 70–86, entirely inboard, in the stator
gap; the −y roller sat at −102 to −86, entirely outboard. **The sled was asymmetric about y = 0**,
and `build_gen5.py --check` passed throughout, because it verifies extents and station positions
and a part misplaced inside an unchanged envelope satisfies both.

**One was a bug in this model**, caught the same way: the track longeron read a parameter that does
not exist, OpenSCAD evaluated it as `undef`, and the beam silently vanished — 88 % of the part's
volume, with no error. That is a real hazard of this tool and it is recorded here rather than
quietly fixed.

## Running it

```bash
python3 cad/tools/make_scad_params.py                     # regenerate from parameters.json
openscad -D 'PART="sled"' -o out.stl cad/scad/gen5.scad   # one part
bash cad/tools/render_scad.sh --headless                  # the PNG set
python3 cad/tools/compare_scad_cadquery.py                # the cross-check
```

`PART` is any of the eight documents, `mechanism` (everything the enclosure hides), or `all`.

## What neither model is

**A geometry and interface model, not a manufacturing model.** No fillets, fasteners, harness
routing or tolerancing exist in either, and `parameters.json` carries no tolerances to give them.
The comparison uses declared tolerances — 0.51 mm on bounding box, 2 % on volume — because
bounding box is exact for both kernels while volume is exact for the B-rep and tessellated for the
CSG, so curved parts carry facet error at `$fn = 96`.

**`compare_scad_cadquery.py` is a tool, not an analysis run.** Its tolerances were written with it,
not declared in advance in a run sheet, so it carries no acceptance bands and is not numbered as an
A-series run. The defect it found stands on its own: a roller outside its channel is wrong at any
tolerance.

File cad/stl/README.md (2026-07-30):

# STL meshes: derived, not authoritative

GitHub renders `.stl` in an interactive viewer and does **not** render STEP, so these two
meshes exist purely so the geometry can be spun in a browser. Click either file above.

**These are derived artifacts.** `../step/gen3/*.step` is the master geometry and
`../parameters.json` is the source of truth for every dimension. A mesh is a faceted
approximation, never measure anything off it.

| File | Source | Mesh size | Triangles | Bounding box |
|---|---|---|---|---|
| `EMOCD_Assembly_Gen3.stl` | `../step/gen3/EMOCD_Assembly_Gen3.step` | 40 mm max | 50,692 | 1995x 530x 940 mm |
| `EMOCD_Sled_Gen3.stl` | `../step/gen3/EMOCD_Sled_Gen3.step` | 8 mm max | 23,332 | 616x 172x 140 mm |

Regenerate with:

```python
import gmsh
gmsh.initialize()
gmsh.option.setNumber('Mesh.CharacteristicLengthMax', 40)   # 8 for the sled
gmsh.option.setNumber('Mesh.CharacteristicLengthMin', 10)   # 2 for the sled
gmsh.option.setNumber('Mesh.Binary', 1)
gmsh.merge('../step/gen3/EMOCD_Assembly_Gen3.step')
gmsh.model.mesh.generate(2)
gmsh.write('EMOCD_Assembly_Gen3.stl')
gmsh.finalize()
```

`pip install gmsh` (its OCC reader handles STEP). On a headless Linux box it also needs
`libglu1-mesa libxft2 libxinerama1 libxcursor1 libfontconfig1`.

Each mesh was checked against its STEP source by bounding box on generation. The sled
matches exactly at 616x 172x 140 mm. The assembly measures 1995 mm in X against a
point-cloud bound of 1998 mm on the STEP, the 3 mm is spline control points lying outside
the surface they define, which is expected and harmless.

**One thing the assembly mesh exposes:** its X range is −188 to 1810 mm, where
`parameters.json` records the installed envelope as −32 to 1807 mm. Something sits 156 mm
further aft than the recorded envelope. See `../../OPEN_PROBLEMS.md` P14.

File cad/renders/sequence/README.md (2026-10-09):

# Gen5 intended-operations media

This folder contains a Blender animation and review graphics made from the FreeCAD-linked Gen5 STEP review solids. The sequence illustrates a proposed order of operations. It does **not** validate a feeder, moving clearance, contact, electromagnetic drive, payload release or sled brake. The evaluated static side-fed placement already **fails** by 11 mm across the enclosure, with 32,915 mm³ exact-solid track/cassette overlap on each side; see [P116](../../../validation/P116_gen5_assembly_packaging.md).

| File | Purpose |
|:--|:--|
| [Four-stage hero](gen5_operations_hero.png) | Website and repository front-page storyboard |
| [Eight-second MP4](gen5_intended_sequence.mp4) | 128 Blender frames at 16 fps, with stage labels and on-screen caveats |
| [Animated GIF](gen5_intended_sequence.gif) | Inline GitHub preview of the same conceptual motion |
| [1200×630 share card](gen5_social_preview.png) | Website Open Graph preview and a prepared GitHub social-preview asset |
| `step_01.png` through `step_04.png` | Representative frames from the four operations |
| [PROVENANCE.json](PROVENANCE.json) and [MEDIA_MANIFEST.json](MEDIA_MANIFEST.json) | Input identity, hidden and moving components, output hashes |

The four illustrated stages are **store** (twelve conceptual payload envelopes), **handoff** (one payload moves laterally toward the common sled), **accelerate** (sled and payload move down the powered track), and **depart** (payload continues while sled stops). The selected payload and sled use scripted straight-line keyframes. The track, interface, stator, brake, remaining payload proxies and far cassette are static. The outer enclosure and near cassette shell are hidden for visibility. No contact, timing, stiffness, control or force solution is implied by the animation.

## Rebuild

1. Export the source-linked review STEP display meshes with `cad/tools/export_step_view_meshes.py` in FreeCAD. Follow [the STEP view procedure](../step_review/README.md) to produce `meshes.json` and its OBJ files.
2. Run `blender -b --factory-startup -P cad/tools/render_gen5_sequence.py -- --mesh-manifest /path/to/meshes.json`. The script checks OBJ hashes and placed bounds against the FreeCAD manifest before rendering. Frames are written to `/tmp/volley-gen5-sequence-frames` and four representative images to this directory.
3. Encode the numbered frames at 16 fps to H.264 MP4 or GIF with ffmpeg. Run `blender -b --factory-startup -P cad/tools/compose_gen5_sequence.py` to compose the hero and share card from the four stage views.

The two Blender scripts and the `MEDIA_MANIFEST.json` preserve the route from STEP to publication asset. The poster and share card are layout renders; they add no engineering evidence. The STEP document itself is a conceptual reference assembly, not a manufacturing release.

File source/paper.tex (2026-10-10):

\documentclass[conference]{IEEEtran}
\usepackage{graphicx}
\usepackage{amsmath}
\usepackage{booktabs}
\usepackage[caption=false]{subfig}
\graphicspath{{figures/}}
\begin{document}

\title{VOLLEY Gen5: A System-Level Computational Feasibility Study of a Programmable Electromagnetic CubeSat Deployer}

\author{\IEEEauthorblockN{Adityavardhan Mishra}
\IEEEauthorblockA{Department of Mechanical Engineering, Symbiosis Institute of Technology\\
Symbiosis International (Deemed University), Pune, India\\
PRN 23070125054}}

\maketitle

\begin{abstract}
Rideshare CubeSats inherit a host orbit; a tailored release impulse could change their initial orbital state. This paper evaluates a twelve-payload 3U electromagnetic deployer as a system-level computational feasibility study, coupling magnetic force, shot and power models, native CAD fit checks, installed mass and a common-input mission screen. The historical periodic-force model predicts a 16.029~m/s shot at 10.07~$g$ and 2.78~kJ gross draw. Finite 3-D analytic integration gives 1.042~kJ of ideal work and a 12.448~m/s geometry-only speed. Independent 2-D finite-element analysis gives 1.082~kJ in-plane work and confirms the end-of-stator force decline, while omitting magnet-depth effects. Coupling the finite-force profile to the assumed historical capacitor model gives 2.099~kJ gross draw for a fully energized winding. A quasi-steady voltage/current screen still fails source power before release at the legacy distributor-data 116--185~m$\Omega$ single-string ESR bound; ideal parallel strings add cells and mass. These are conditional model screens, not a verified motor rating. The modeled 126.6~kg dry mass amounts to 10.547~kg per 3U payload, failing both the internal 2~kg screen and an approximate 6~kg spring-canister comparison. The side-fed reference CAD requires 11~mm more internal width and has track--cassette interference; an unselected wider geometry candidate does not close feed actuation or installed mass. No option closes the bounded twelve-shot matched mission. An independently checked 28.800775~km two-body semi-major-axis rise applies only to an \emph{assumed} historical 16.029~m/s release, not to demonstrated Gen5 capability or atmospheric lifetime. The evaluated Gen5 configuration therefore fails selection for this 3U case; a one-event resized-fuel comparison remains 52.717~kg heavier on device plus fuel than the spring reference. An independent depth-resolved 3-D surface-charge numerical formulation reproduces the ideal 1.042~kJ work; a 14~mm face gap instead of 12~mm reduces it to 0.907~kJ. Selected winding/inverter, release-contact and host-interface closure remain open; no VOLLEY hardware has been built or tested. Gen6 high-speed targets are future research.
\end{abstract}

\begin{IEEEkeywords}
CubeSat deployment, electromagnetic launch, Halbach array, linear synchronous motor, rideshare, constellation phasing, small launch vehicles.
\end{IEEEkeywords}

\section{Introduction}
Rideshare secondary payloads may be released into an orbit selected by the primary mission rather than their own target \cite{soa}. Conventional spring dispensers supply a small, payload-dependent separation impulse; flight-proven examples include J-SSOD and commercial CubeSat deployers \cite{jssod,exopod}. An operator needing different delivered states can also use host manoeuvres, onboard propulsion, differential drag or an orbital-transport service. A useful deployer comparison must hold payloads, starting orbit, final-state tolerances, deadline, integration burden and failure consequences constant. Repeatable small-satellite fleets are a plausible mission context, but no customer, payload or host has endorsed the Gen5 requirements in this paper.

Electromagnetic release is established prior art, not a novelty claim in itself. Feng \emph{et al.} model a high-acceleration induction launcher for a 20~kg CubeSat \cite{feng2025}; other work studies stacked-spacecraft transfer and reports a transport-mechanism prototype \cite{stacked2022,xu2024,storage2025}. The question investigated here is narrower: can a shared host-mounted device impart a modelled, individually commanded impulse to an unmodified 3U payload while meeting a chosen acceleration limit and system-level mass, power, containment and mission criteria? The 25~$g$ ceiling is a design choice, not a universal CubeSat qualification limit; the CubeSat Design Specification defers acceptance to the mission provider \cite{cds}.

This paper evaluates one fixed Gen5 computational configuration. It contributes a modeled machine and shot, selected field and circuit cross-checks, a mass and orbit trade, a reference assembly with an explicit packaging failure, and a register of conditions that prevent a product or flight claim. Host examples are reference calculations, not approved interfaces. The current results include negative design findings rather than a demonstrated customer benefit. The rated shot is retained as a historical model result; a new finite-stator screen challenges its use as a defensible performance prediction.

\section{Related Work}
\subsection{Deployment heritage}
The P-POD established the rail-and-spring standard, and the ISS-based J-SSOD and NanoRacks systems industrialized it \cite{jssod,soa}. The failure record is instructive: the NanoRacks ball-lock anomaly, in which jack-screw preload above 0.11~N$\cdot$m drove the release mechanism toward seizure, traced to a load path in which ascent preload passed through the release device itself \cite{lewis}. Zhao \emph{et al.} built a multi-CubeSat electromagnetic transport-and-ejection prototype and report selectable separation speeds of 0.4--0.85~m/s for 3U and 0.67--1.42~m/s for 1U payloads \cite{stacked2022}. Programmable electromagnetic release and stacked feed are therefore prior art. Gen5 has a historical 16.029~m/s 3U periodic-force shot prediction within a different modeled installed-system design; its finite-geometry screen challenges that speed, and it has no measured shot and fails its own 3U mass and side-fed packaging criteria.

\subsection{Electromagnetic launch and supporting technology}
Coilgun research examined nanosatellite launch at km/s scales \cite{turman,kaye}, establishing contactless acceleration and its costs: the single-stage reluctance machines of that lineage convert 1--2\% of stored energy into kinetic energy, though multi-stage induction designs do far better, and the on-orbit CubeSat launcher of \cite{feng2025} reports 14.9--19.9\%. Ironless permanent-magnet linear machines occupy the opposite corner of the design space: the Halbach array concentrates flux on one working face \cite{halbach}, and the Inductrack program demonstrated large forces from such arrays with no iron and no sliding contact \cite{inductrack}. Finite Halbach arrays can introduce end-effect thrust ripple \cite{yamaguchi2023}, motivating a position-dependent 3-D force check for Gen5 rather than an imported correction factor. Space-oriented supercapacitor studies and component options are reported in ESA-led programmes \cite{faure,espc}, but no installed Gen5 cell string is qualified. Eddy-current damping has aerospace precedent \cite{eddy}; the proposed VOLLEY brake has not been tested. On the astrodynamics side, Planet Labs demonstrated propulsion-free constellation phasing by differential drag over campaigns of weeks to months \cite{foster,foster2}; that timescale is the benchmark against which impulsive seeding is measured. ISRO's POEM programme converted the spent PSLV fourth stage into a stabilized hosted-payload platform across four missions, closing POEM-3 with a controlled, debris-free reentry \cite{poem3,poem4}, providing a hosted-stage precedent, not regulatory approval for VOLLEY.

\section{System Architecture}
\subsection{Requirements}
The driving requirements are: eject an unmodified 3U CubeSat, imposing no armature, plating, or electrical interface on the customer satellite; hold payload acceleration below a \emph{chosen} design ceiling of 25~$g$, a requirement this work sets on itself rather than one any standard imposes; mount on a restartable upper stage, kick stage, or hosted orbital platform through a standard ESPA bolt pattern, a host class whose accommodation envelope is not public and against which the closed 1839~mm length therefore cannot yet be shown to fit (Sec.~\ref{sec:lim}); provide per-satellite programmable velocity with dispersion small against its astrodynamic effect; carry a twelve-satellite manifest with autonomous sequencing; provide inhibits and a defined abort; and hand recoil to the host in a form its attitude control absorbs at negligible propellant cost.

\subsection{Derivation of Principal Design Parameters}
The values that define the machine combine internal requirements, assumptions and externally sourced limits; Table~\ref{tab:derive} records the governing relation for each. Three deserve explicit statement. The acceleration ceiling is \textbf{chosen, not derived}. An earlier version of this work obtained it by integrating the NASA GEVS \cite{gevs} protoflight random-vibration spectrum to 14.1~$g_{\mathrm{rms}}$, taking a $3\sigma$ envelope of roughly 42~$g$ as the launch load, and setting a 25~$g$ cap beneath it. \textbf{That derivation is withdrawn.} Broadband random vibration and a 162~ms commanded acceleration are different load cases: $g_{\mathrm{rms}}$ is the root-mean-square of a stationary random process over a spectrum, and multiplying it by three produces a peak-response estimate for that process, not a quasi-static limit load a structure is qualified to carry. Neither GEVS nor the CubeSat Design Specification \cite{cds} publishes a universal quasi-static level for CubeSats; the CDS defers test levels to the launch provider, and levels therefore vary by vehicle and by mission. \textbf{25~$g$ is retained here as an internal design requirement} --- the number the retention chain, the cradle, the abort logic and the payload-family table are all sized against --- and it is not offered as evidence that any satellite is qualified for it. An earlier version of this design was acceleration-limited: at a 4.9~kg parametric sled the ejection ran at 16.3~$g$, close enough to the cap that the cap set the velocity through $v_{\max}=\sqrt{2a_{\max}L}$. That is no longer the binding constraint. With the sled computed at 9.4~kg from the CAD solid volumes the same commanded force accelerates a heavier moving mass, so the ejection sits at 10.1~$g$ and the 1.3~m zone yields 16.0~m/s. The machine is now \emph{thrust-and-mass} limited rather than acceleration-limited, with a factor of 2.5 of margin against its own ceiling left unused. Recovering velocity therefore means removing sled mass or raising sheet current, not shortening the stroke; a 0.2~m coast-trim zone completes the 1.5~m axis. Stroke buys velocity only as $\sqrt{L}$, so the trade is unattractive: total track lengths of 1.0, 1.2, 1.5 and 1.8~m give 12.6, 14.1, 16.0 and 17.8~m/s respectively, and the envelope is already the binding packaging constraint (Sec.~\ref{sec:lim}). The capacitor bank follows from the shot energy and the droop it actually reaches: at the 2.78~kJ draw the selected 6~F bank sags to $V_1=0.947V_0$, and
\begin{equation}
C=\frac{2E}{V_0^2-V_1^2}=6.00~\mathrm{F}\rightarrow 6~\mathrm{F},
\end{equation}
realized as thirty-two series 190~F, 3~V commercial cells for a 96~V rail compatible with 1200~V SiC devices at a comfortable derating.

\begin{table}[t]
\caption{Governing relation for each principal parameter}
\label{tab:derive}
\centering\scriptsize\setlength{\tabcolsep}{4pt}
\begin{tabular}{lll}
\toprule
Parameter & Value & Set by\\
\midrule
Accel. ceiling & 25 $g$ & \emph{chosen} design limit (Sec.~III-B)\\
Track length & 1.5 m & $v=\sqrt{2aL}$ + coast zone\\
Rail material & 7075-T6, hard anodize & CDS rail spec \cite{cds}\\
Bank voltage & 96 V & SiC 1200 V derated 60\%\\
Bank capacitance & 6 F & droop eqn (2), $\le$5\% SoC sag\\
Sled magnets & N45SH & thermal $\times$ field (Sec.~V-F)\\
Brake cap & 200 $g$ sled & magnet bond MoS (Sec.~III-F)\\
Abort point & 45\% stroke & braking-distance equality\\
Magazine & 12 (2$\times$6) & cassette CoM symmetry\\
\bottomrule
\end{tabular}
\end{table}

\subsection{Topology Trade}
The payload settles the trade before the electromagnetics do. Exit velocity is bounded by
\begin{equation}
v_{\max}=\sqrt{2\,a_{\max}L},
\end{equation}
so at the 25~$g$ design ceiling over a 1.3--2~m stroke the reachable range is 25--31~m/s. The coilgun's defining advantage, a km/s-class ceiling, is outside this Gen5 payload load envelope, while its costs remain: microsecond timing against the suck-back effect, an armature bolted to the customer's satellite, and no abort once fired. Efficiency is deliberately not among them: at 14.9--19.9\% \cite{feng2025} a multi-stage coilgun is comparable to the figure reported here, and an earlier version of this argument claimed otherwise on the strength of a single-stage number. A linear synchronous motor concedes nothing in the reachable envelope and inverts every cost: high drive efficiency, continuous servo control, and a reusable sled that carries the magnets so the satellite carries nothing. Table~\ref{tab:trade} summarizes.

\begin{table}[t]
\caption{Topology trade. The velocity row is evaluated at this design's chosen 25~$g$ ceiling, not at a qualification limit of the payload}
\label{tab:trade}
\centering\scriptsize\setlength{\tabcolsep}{4pt}
\begin{tabular}{lcc}
\toprule
Criterion & Reluctance coilgun & Ironless LSM + sled\\
\midrule
Velocity at the 25 $g$ ceiling & 25--31 m/s & 25--31 m/s\\
Electrical$\rightarrow$payload efficiency & 14.9--19.9\% \cite{feng2025} & 18.8\% (Sec.~V)\\
Satellite modification & armature required & none\\
Velocity control & pulse timing & closed-loop servo\\
Abort & none once fired & to $\sim$45\% stroke\\
Field on stored satellites & pulsed, unshielded & Halbach self-shielded\\
\bottomrule
\end{tabular}
\end{table}

\subsection{Layout and Firing Cycle}
The model places the release station 1.5~m from the breech on 1.8~m structural longerons; the powered stroke is 1.3~m, followed by a 0.2~m coast-and-trim interval (Figs.~\ref{fig:block} and \ref{fig:layout}). The stator is a double-sided ironless three-phase winding. The modeled mover is a 9.445~kg sled carrying opposed Halbach arrays (48~mm wavelength, 8~mm N45SH blocks, four blocks per wavelength) across a 12~mm winding gap. The two six-satellite cassettes are conceptual feed elements. Their current side-fed reference placement fails the width and exact-solid interference checks reported in Sec.~\ref{sec:lim}. Figure~\ref{fig:cadreview} shows the STEP-derived reference placement with the enclosure hidden; its surface shading is a visualization rather than hardware evidence.

The intended sequence is follower advance, restraint engagement, motor acceleration, sled braking and payload departure. Feed forces, contact transitions, retention during ascent, release timing and tip-off have not been verified for an actual satellite. The current model assumes that the payload remains seated against the aft backstop during acceleration and separates when the sled decelerates; that assumption requires moving-contact analysis and instrumented tests. The ideal internal mass-motion model gives no final rigid-body rate after the sled stops, but it predicts a transient return rate of 0.130~deg/s for the assumed 500~kg host and 0.385~deg/s at 200~kg; both declared peak-rate bands fail. The earlier 8.2~s rate-null and 18.1~s cadence floor are superseded. An assumed 166~mm lever arm gives a 0.40~deg attitude offset in the 500~kg example. Controller restoration time and structural ringing have not been established. The adopted mission-planning interval is 1200~s between shots; 10--20~s is only a modeled recharge floor, so twelve scheduled shots span approximately 4.0~h and 2.6 orbits if all other operations succeed.

\begin{figure}[t]
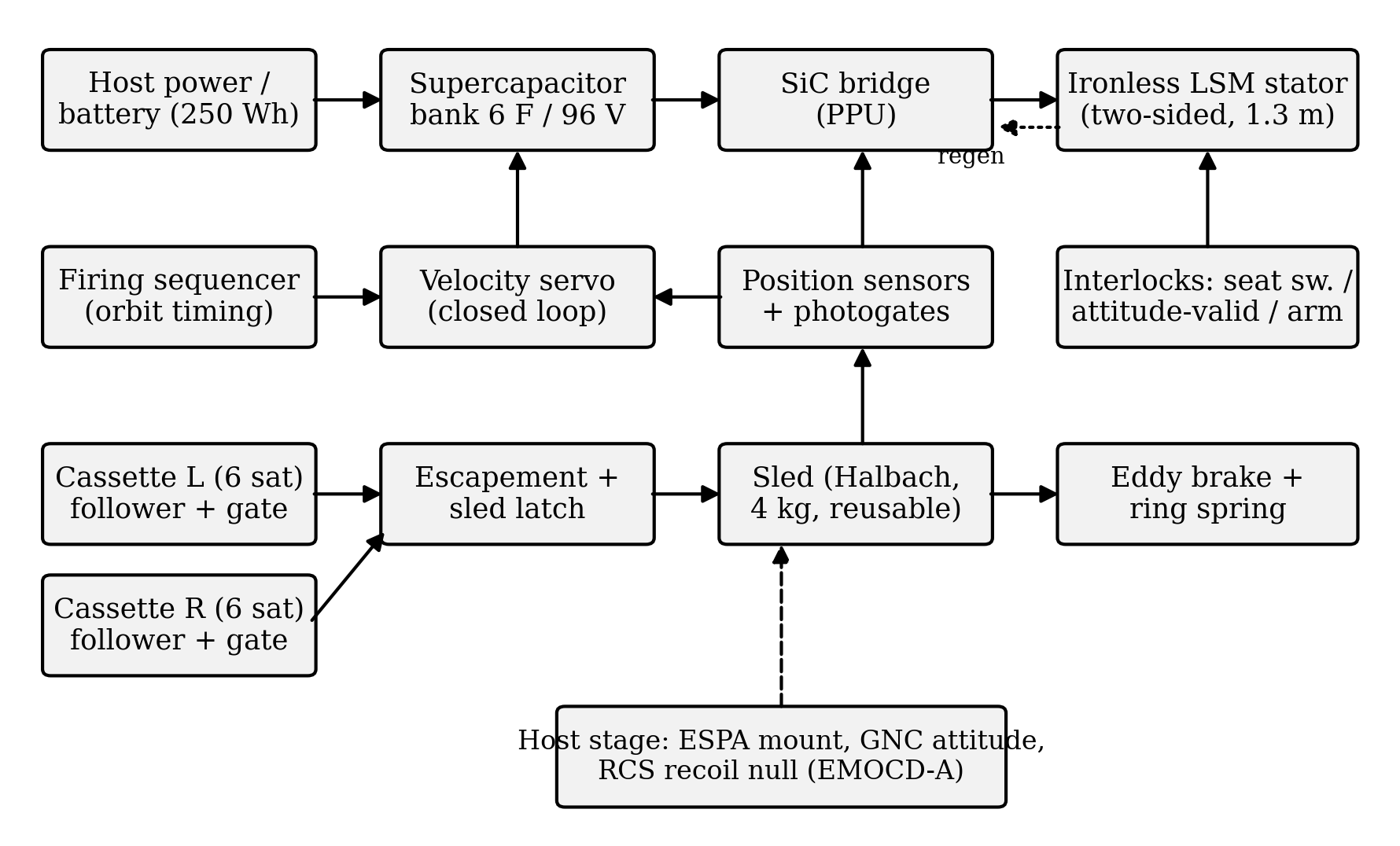
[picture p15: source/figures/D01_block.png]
\centering
\caption{System block diagram: power, control, mechanism, and host-interface chains.}
\label{fig:block}
\end{figure}

\begin{figure}[t]
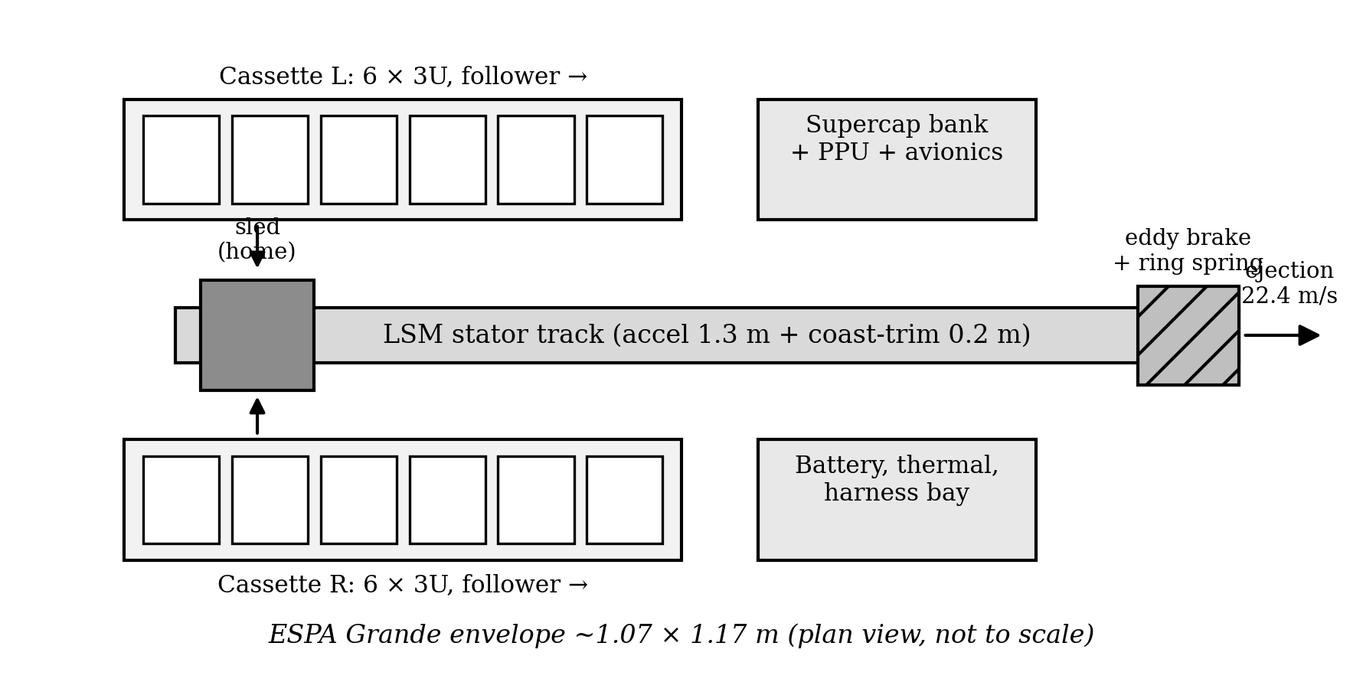
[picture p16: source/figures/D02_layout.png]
\centering
\caption{Plan-view layout against an ESPA-Grande-class envelope (not to scale), retained as a dimensional reference. The closed envelope exceeds that class in length by 44\%; ESPA-Grande port compliance is not a requirement of this design, and the target host class is discussed in Sec.~\ref{sec:lim}.}
\label{fig:layout}
\end{figure}

\begin{figure}[t]
\centering
\caption{Twenty-instance Gen5 reference assembly visualized in Blender after FreeCAD read-back of named STEP solids. The enclosure is hidden to expose the track and side cassettes. Their evaluated placement has a documented exact-solid interference; the image is geometry visualization, not a built or qualified mechanism.}
\label{fig:cadreview}
\end{figure}

\subsection{Restraint, Inhibits, and Abort}
Launch restraint separates the preload path from the release path, the inverse of the NanoRacks fault \cite{lewis}. One-shot retention gates at each cassette exit carry ascent preload directly into structure; the escapement is caged during ascent; the sled is held by a motorized over-center cam lock. Firing requires a three-inhibit chain: redundant seat switches, an attitude-valid flag from the host, and a sequencer arm. Abort is available to approximately 45\% of the stroke, beyond which braking distance for the combined mass exceeds remaining track; the muzzle buffer is sized to capture an aborted combined mass. The retention gate carries the ascent preload of a six-satellite stack through two D9 A-286 shear pins of 41.0~kN double-shear capacity; the escapement, caged behind the gate, sees none of this. The quasi-static case taken at this design's own 25~$g$ ceiling, $24\,\mathrm{kg}\times25\,g=5.9$~kN, is \emph{not} the sizing case, and the gate was originally sized against it with two D6 pins. Miles' equation on the GEVS protoflight spectrum (14.1~$g_\mathrm{rms}$, 0.16~$g^2$/Hz) at the track's 109~Hz fixed-fixed mode gives a 3$\sigma$ load of 11.7~kN at $Q=10$ and 20.2~kN at $Q=30$, two to three and a half times the quasi-static figure, which left the D6 margin negative at $Q=30$. The pins were not undersized; the load case was. Resizing to D9 raises the margin of safety to $+0.45$ at $Q=30$ and keeps it positive across $Q=10$--$30$ for an added mass of 11~g, so the retention chain no longer depends on where the unmeasured structural damping lands---which matters because the same unmeasured $Q$ governs the force-ripple resonance discussed in Sec.~\ref{sec:lim} and cannot be resized away there. Random vibration, not quasi-static preload, is the driving case for the retention chain, and is now the case it is sized against. The abort threshold is where the sled braking distance under the same thrust equals the remaining track, which for the loaded 13.4~kg carriage falls at 45\% of stroke and 11.1~m/s. The commit fraction is unchanged by the heavier sled---braking distance and travelled distance scale with mass identically, so the mass cancels---but the velocity at the commit point falls with the acceleration.

\subsection{Arrest, Power, and Materials}
The sled leaves release with about 1.21~kJ. Motor regeneration alone cannot arrest it, because braking force is bounded by the same thrust constant as acceleration; that bound sets what regeneration can and cannot do, and both halves matter. Braking at the rated sheet current over the 39~mm of stator the closed envelope allows downstream of release extracts 51.8~J of mechanical work for 0.4~J of copper, returning \textbf{47~J} to the bank, and the sled still reaches the brake at 15.7~m/s carrying \textbf{1162~J}. A copper-fin eddy-current brake therefore provides bulk arrest: force proportional to velocity, contactless, with flight heritage in the damper class \cite{eddy}. Authority is abundant, so the pole entry is tapered to cap sled deceleration near 200~$g$. This limit is set by the magnet retention: a 65~g Halbach block at 200~$g$ loads its bonded interface (10.8~cm$^2$) to only 0.12~MPa against a conservative 10~MPa epoxy allowable, a margin of 84, so 200~$g$ is a deliberate conservatism protecting the brittle sinter rather than a strength limit. The 0.344~kg copper fin absorbs the sled's residual 1162~J per shot at an adiabatic 9.0~K per-shot transient rise; cooling between shots has not been modelled; a ring-spring catches the residual below 1.5~m/s (Fig.~\ref{fig:brake}). Pulse energy comes from a 6~F, 96~V supercapacitor bank switched by a SiC bridge \cite{faure}. Materials follow three rules: nothing conductive rides the changing field (titanium sled chassis, PEEK formers), nothing near the track is ferromagnetic except by design (BeCu springs, A-286 fasteners), and nothing outgasses near customer optics (E595-compliant polymers, dry films, sealed roller cartridges).

\begin{figure}[t]
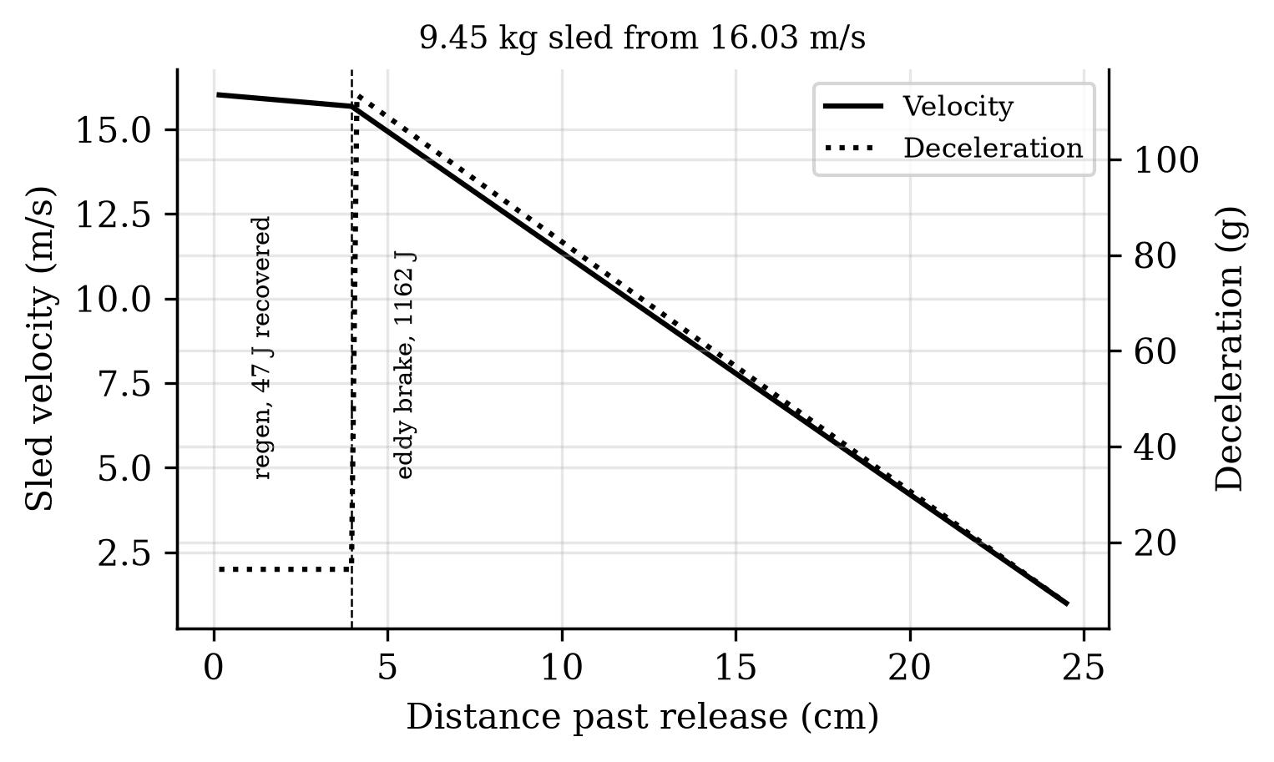
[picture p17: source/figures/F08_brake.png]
\centering
\caption{Eddy-brake arrest, taper-limited to 200~g on the sled.}
\label{fig:brake}
\end{figure}

\section{Models and Verification}
\subsection{Field Model and Independent Verification}
The Halbach airgap field is a decaying wave, $B(y)=B_0e^{-ky}$ with $k=2\pi/\lambda$, summed over the two opposed faces. Because this carries the force budget, it was checked against an independent magnetostatic computation (analytic cuboid superposition, magpylib), with the array rotation-sense convention determined empirically by probing a single array on both faces; the exercise caught two successive sign errors whose outputs matched single-array fingerprints. Converged results: single-array mid-gap 0.351~T against the wave model's 0.351~T; double-sided mid-gap peak 0.694~T against a predicted 0.702~T. The stray field behind the array back face, which sets the magnetic keep-out for stored satellites, computes to 22.7~mT at 10~mm, 4.3~mT at 20~mm, and 0.4~mT at 50~mm.

\subsection{Winding-Resolved Thrust Constant}
The airgap field is sampled in all three dimensions before the Lorentz sum: $B_y$ is Gauss-Legendre averaged across the array's full 90~mm depth rather than taken on the centre plane. That distinction is worth stating because the centre-plane value is 4.4\% higher, and using it---as this work did until an independent depth-resolved integral was run---overstates the thrust constant by the same margin and the exit velocity by 2.2\%.
A slotless three-phase belt winding (pole pitch $\lambda/2$, belts of $\lambda/6$, winding factor 0.955) was resolved against the verified field by direct Lorentz integration with position-locked sinusoidal commutation, the field translated with the sled. The result is a thrust constant
\begin{equation}
K_t = 10.54~\mathrm{N/(kA/m)},\quad \text{ripple } \pm1.01\%\ (6\text{th harm.}),
\end{equation}
shown in Fig.~\ref{fig:ripple}. Fig.~\ref{fig:fieldmap} shows the field the integral is taken over, and the reason the integral must be taken over it: sampled on the array's centre plane $B_y$ peaks at \textbf{0.5041~T}, while the mean across the 90~mm depth is \textbf{0.4759~T}, a ratio of \textbf{0.9440}. Treating the centre-plane value as though it held across the depth is the 4.42\% overstatement Sec.~\ref{sec:lim} records.

\begin{figure*}[t]
\centering
\caption{Halbach airgap field. Left, $B_y$ in the $x$--$y$ plane over one wavelength; right, the profile through the array's 90~mm depth. Drawn by the same field builder the thrust integral uses, so the two cannot disagree.}
\label{fig:fieldmap}
\end{figure*} Synchronous extraction carries the one-half traveling-wave factor that lumped $\langle B\rangle KA$ models hide; the corrected constant is recovered operationally by rating the sheet current at 140~kA/m and commanding 126~kA/m (21~A/mm$^2$ pulse-only in the copper), where adiabatic heating remains \textbf{0.35~K} per 162~ms shot: the shot's 854~J of copper loss into the 6.29~kg of stator copper at 385~J/(kg$\cdot$K), quoted to two significant figures throughout as 0.3527~K computed. An earlier version of this section rounded it to 0.3~K while Sec.~\ref{sec:thermal} carried 0.35~K; the two are the same number and the paper now states it once.

\begin{figure}[t]
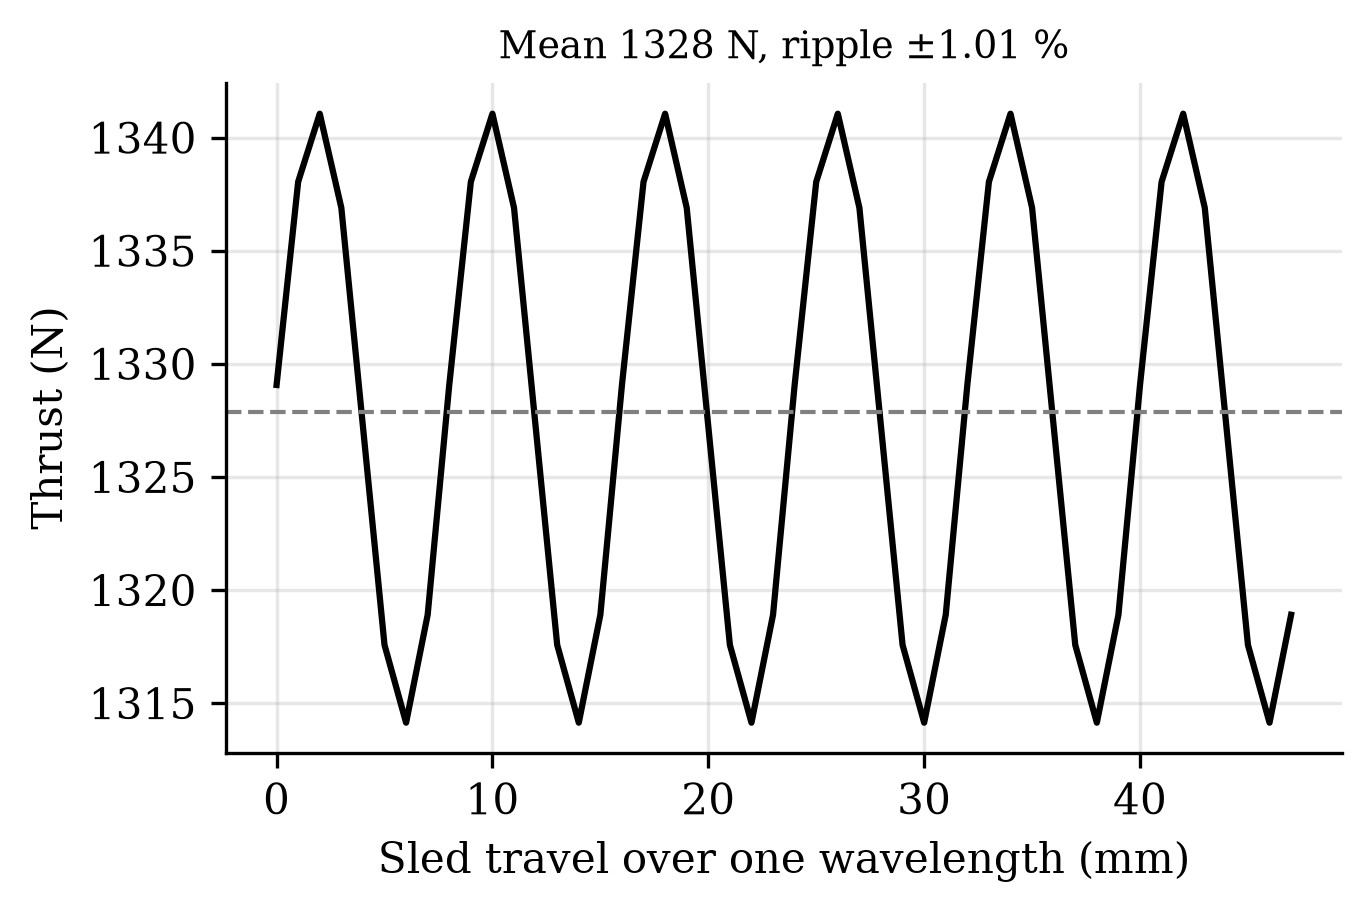
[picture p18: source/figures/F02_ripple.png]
\centering
\caption{Winding-resolved thrust over one wavelength of sled travel.}
\label{fig:ripple}
\end{figure}

\subsection{Shot, Servo, and Astrodynamic Models}
The shot integrates sled-plus-satellite dynamics against the supercapacitor circuit with explicit copper loss and a 95\% converter. Velocity control uses a position-scheduled profile with proportional correction and a coast-trim residual correction from photogate measurement; an 800-run Monte Carlo over thrust-constant, mass, force-ripple, and sensor tolerances gives the dispersion. The proportional gain is not tuned to that dispersion but designed against stability margins, as Sec.~\ref{sec:control} sets out. Orbital lifetime uses per-revolution orbit-averaged decay (Gauss tangential equations, quadrature over eccentric anomaly, static exponential atmosphere at mean activity \cite{vallado}); the method was cross-validated against an independent Cowell RK4 propagation with drag, the two agreeing on 30-day semi-major-axis decay to 99.4\%. Constellation seeding uses $\Delta a = 2a\,\Delta v/v$ and the resulting period difference; deployment safety propagates the stage and all deployed ellipses with Kepler-plus-secular-$J_2$ motion for 30 days, with candidate minima refined at 0.25~s sampling.

\subsection{Velocity-Loop Stability}\label{sec:control}
The control law divides the commanded sheet current by the modelled thrust constant and multiplies by the modelled mass, so the plant's own $K_t/m$ cancels and the open-loop transfer reduces to $L(s)=K_p\,e^{-s\tau}/s$. The proportional gain is therefore not a current gain but an acceleration per unit velocity error, in $\mathrm{s^{-1}}$, and \emph{its numeric value is the gain crossover frequency in rad/s}. The total lag $\tau$ is the sensing and computation transport delay plus the half-sample of a zero-order hold; both are pure delays and add. No sensor has been selected, so the delay is a stated assumption, swept rather than asserted, and 0.6~ms is used as the reference value with a 0.1~ms hold at 5~kHz.

That reduction sets the design constraint. An earlier gain of 3500~$\mathrm{s^{-1}}$ places the crossover at 557~Hz---five times the track's 109~Hz first bending mode and above the 48~Hz mode as well---giving $-50.4^\circ$ of phase margin and $-3.9$~dB of gain margin at the reference delay, with marginal stability reached at only 0.45~ms of total lag (Figs.~\ref{fig:bode} and \ref{fig:lat}). Two properties of the simulation had concealed this: the loop fed back an undelayed state, which is the one condition under which that gain is stable, and the command is clipped at the winding rating, so the linearly unstable loop behaves as a bang-bang relay whose mean follows the feedforward term while the terminal photogate trim removes the residual. The reported dispersion was consequently governed by the saturation limits and the terminal correction rather than by the feedback it was attributed to, which is why the closed-loop figure is reported here only alongside the margins that make it a property of a design.

The gain is instead sized as the largest value simultaneously holding $\geq 50^\circ$ of phase margin at the reference delay and keeping closed-loop bandwidth at or below one third of the first bending mode, which gives 195~$\mathrm{s^{-1}}$: crossover 31.1~Hz, phase margin $+82.2^\circ$, gain margin $+21.2$~dB, and no excursion above the current rating anywhere in the stroke. \textbf{The gain falls by a factor of eighteen and the $3\sigma$ dispersion does not move}, 0.0271 to 0.0267~m/s. The loop never required the bandwidth: dispersion is set by the terminal trim and by the thrust-constant and mass tolerances, not by loop gain. The binding constraint is now the structural one, so a measured first mode below 109~Hz would lower the designed gain with it. Classical margins on a 162~ms trajectory are necessary rather than sufficient, the plant is treated as rigid, and the structural modes enter only as a frequency the bandwidth is held away from; a compliant-track model remains outstanding.

\begin{figure}[t]
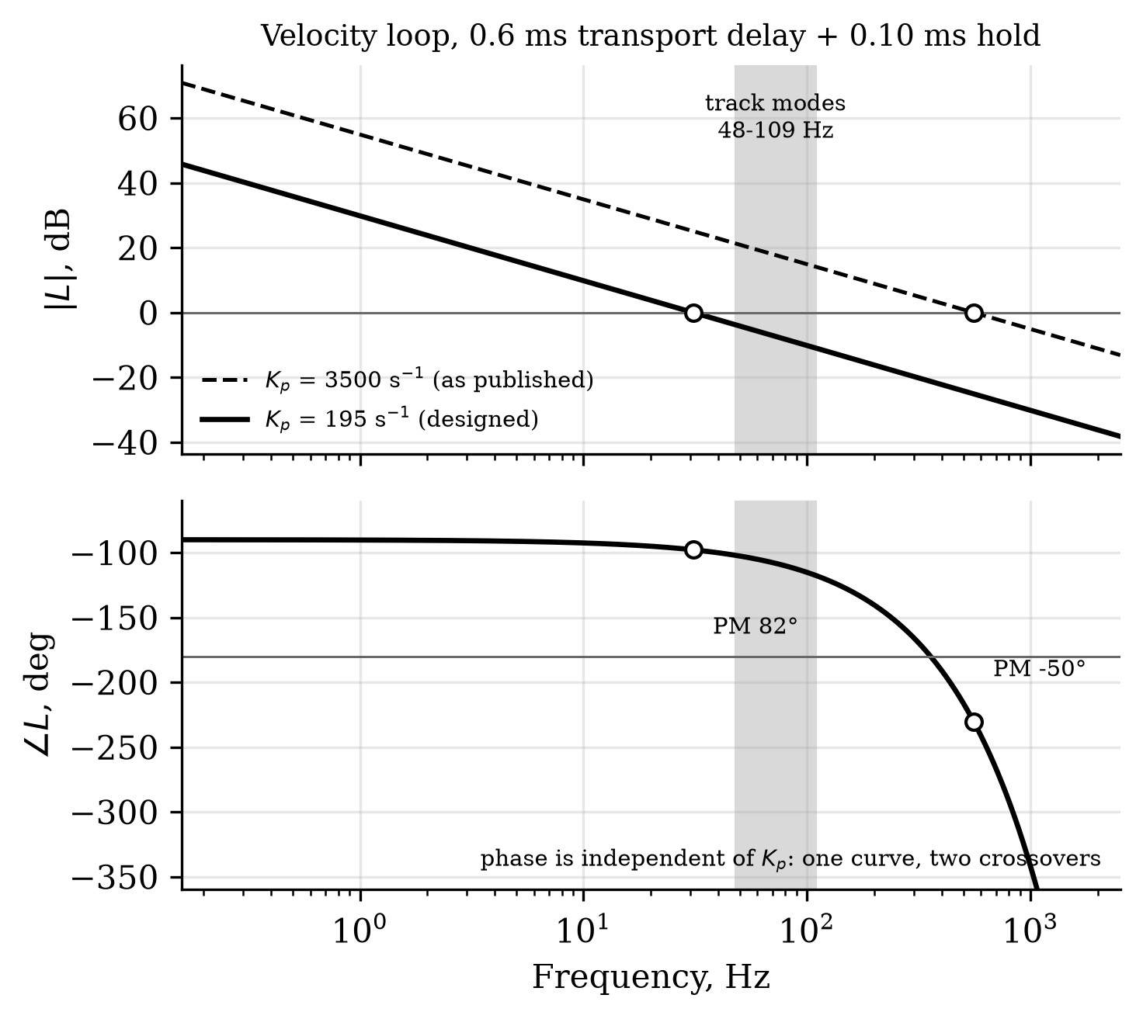
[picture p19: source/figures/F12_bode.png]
\centering
\caption{Open-loop velocity-loop response at the earlier and the designed gain, with the 48--109~Hz band of track modes shaded and both gain crossovers marked. Phase depends only on frequency and delay, so the two gains share one phase curve.}
\label{fig:bode}
\end{figure}

\begin{figure}[t]
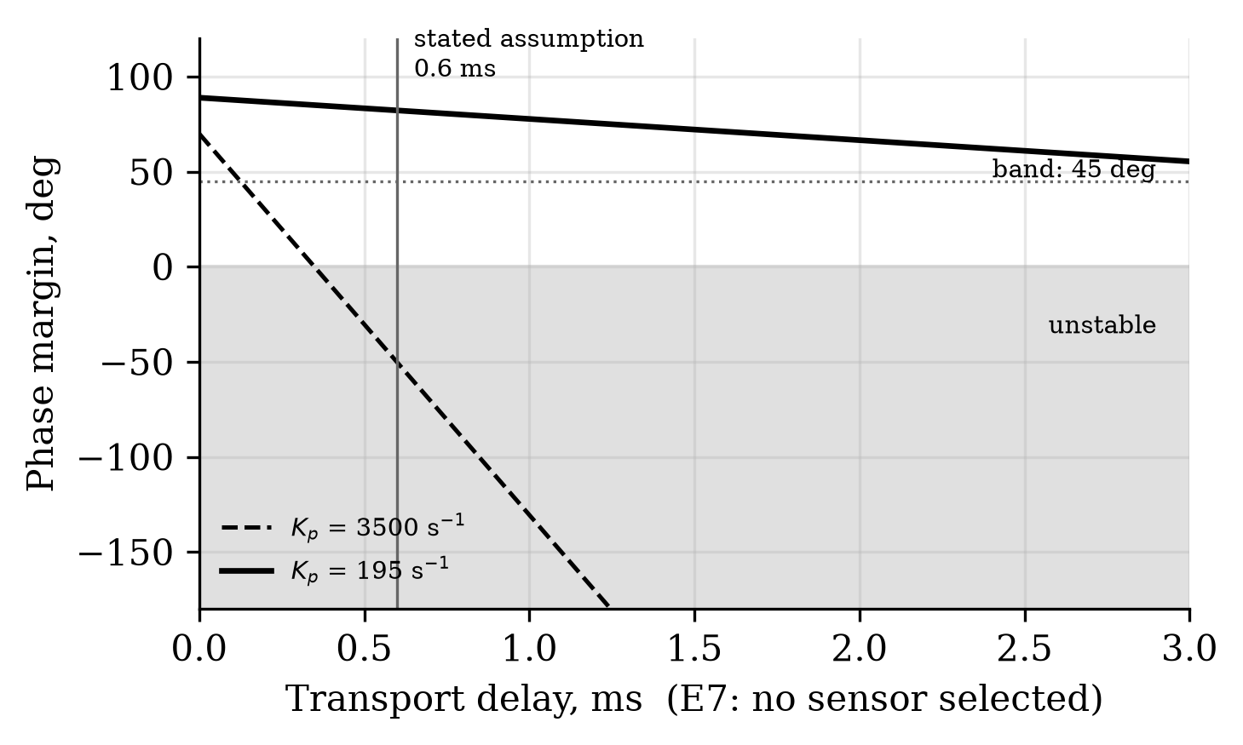
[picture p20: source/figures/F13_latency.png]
\centering
\caption{Phase margin against transport delay. The earlier gain crosses into instability at 0.35~ms of transport delay; the designed gain holds more than $55^\circ$ across the whole swept range.}
\label{fig:lat}
\end{figure}

\section{Performance Results}
\subsection{Historical Periodic-Model Shot}
The following values belong to the historical periodic-force shot and are not a verified Gen5 rating; the finite-geometry screen in Sec.~\ref{sec:finite} challenges their force input. At that modeled point (3U reference, 9.445~kg sled input from historical Gen3 CAD solid volumes, 1.3~m acceleration): exit velocity \textbf{16.0~m/s} at \textbf{10.1~g}, pulse 162~ms, peak current 320~A, and bank state-of-charge sag 5.2\% (Fig.~\ref{fig:shot}). Energy drawn is 2.78~kJ per shot, with copper heat of 854~J and a further 76~J dissipated in the bank's own series resistance. Regenerative braking returns 47~J after release, so the net draw is 2.74~kJ. The payload receives 514~J, a \textbf{18.8\% electrical-to-payload efficiency}; the sled's share is split between 47~J recovered and 1162~J dissipated in the arrest brake. Efficiency falls with the heavier sled for two compounding reasons: a larger fraction of the same mechanical work goes into a mass that is then braked away, and the longer 162~ms pulse accrues more copper loss at unchanged current density. Recovery is what partially offsets the first of those, and it is bounded by geometry rather than by loss: over the available 39~mm the braking pulse lasts 2.5~ms and burns 0.4~J of copper, against 854~J over the 162~ms shot, so recovered energy rises monotonically with braking force up to the winding's rating and with distance beyond it. A 500~mm section would return 540~J and a 1~m section would arrest the sled outright while returning 727~J, but the closed envelope already exceeds its target class by 44\% (Sec.~\ref{sec:lim}), so distance is not available here. Peak current during recovery is 212~A, below the shot's own 320~A, so the drive is not re-rated. The closed-loop Monte Carlo returns a dispersion of \textbf{0.0274~m/s (3$\sigma$)} at a 15.8~m/s fleet setpoint (Fig.~\ref{fig:mc}), dominated by the sensing chain rather than plant tolerances. The setpoint must sit below the open-loop ceiling for the servo to retain authority; at 98.85\% of it, the nominal headroom is 0.188~m/s. Table~\ref{tab:family} gives the payload family: the system is force-limited above 1U, so heavier payloads trade modeled velocity under the internal 25~$g$ ceiling; actual structural compatibility is unverified, and the deployer mass each customer pays for varies by a factor of 109 across the family (Sec.~\ref{sec:family}).

A separate local algebraic audit recalculates the payload kinetic energy, constant-acceleration equivalent stroke, dry-mass sum and brake-work identities from the captured JSON. These agree within the declared rounding bands. The compact output leaves 124.488~J (4.47\%) after those terms, now reconciled to 90.964~J assumed converter loss, 32.460~J auxiliary draw and 1.064~J forward-Euler integration excess. The rounded residual is below 0.001~J. This closes the historical model arithmetic, while an actual power source and the revised finite-force circuit remain unverified.

\begin{figure}[t]
\centering
\caption{Historical periodic-model shot profile: (a) velocity with coast-trim zone; (b) bank voltage and current.}
\label{fig:shot}
\end{figure}

\begin{figure}[t]
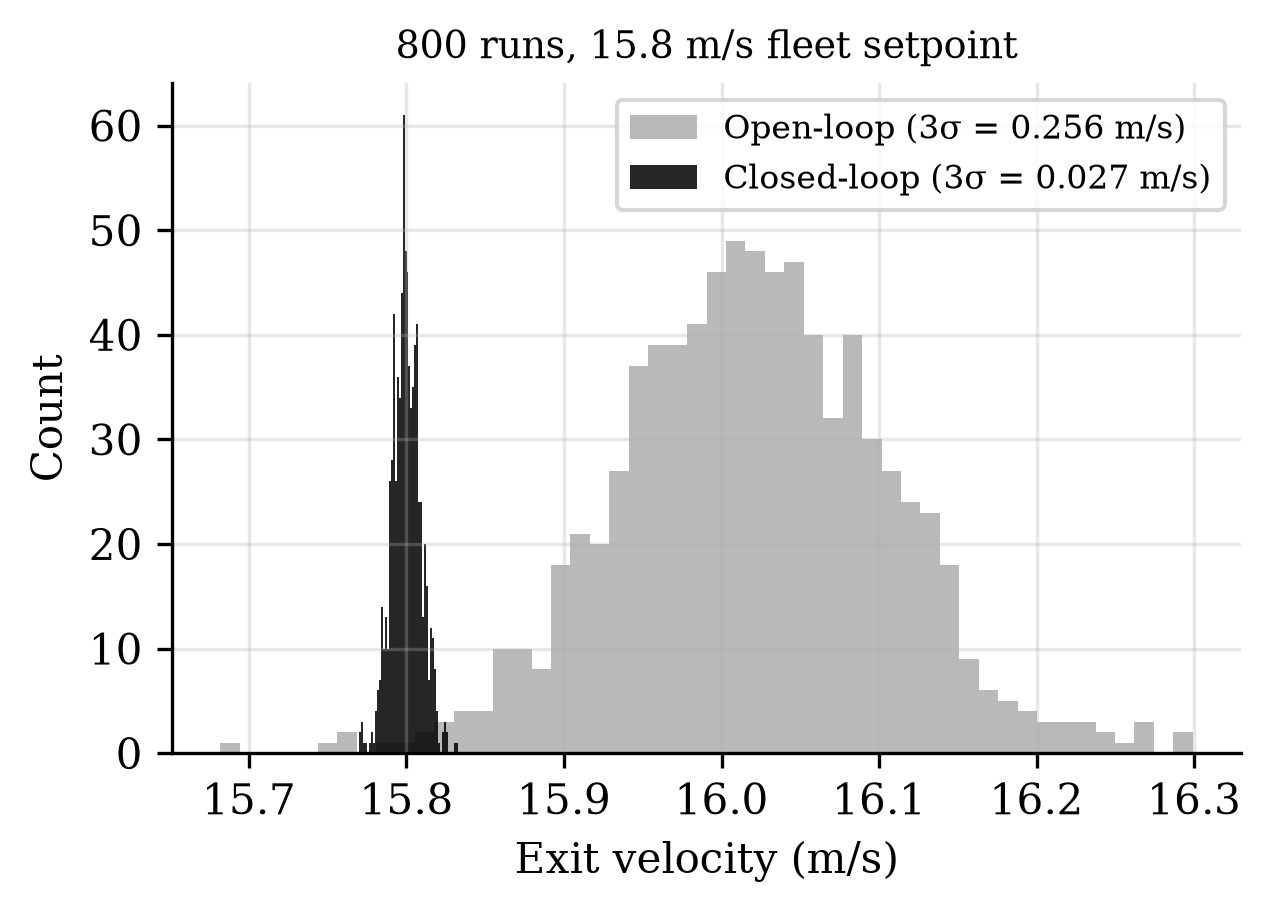
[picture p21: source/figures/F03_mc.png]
\centering
\caption{Closed-loop exit-velocity dispersion, 800 Monte Carlo runs.}
\label{fig:mc}
\end{figure}

\begin{table}[t]
\caption{Historical periodic-model payload-family screen (1.3 m acceleration, 9.445 kg CAD-derived sled). Deployer mass per satellite uses the 126.6 kg dry mass and a packing model calibrated so the 3U case returns the twelve the magazine is laid out for. Every column is regenerated from \texttt{payload\_family.json} at the current operating point; the values published until 2026-08-20 predated both ADR-030 and the enclosure buildup}
\label{tab:family}
\centering\footnotesize
\begin{tabular}{lccrr}
\toprule
Class & Exit vel. & Accel. & Per load & kg/sat.\\
\midrule
PocketQube 1P (0.25 kg) & 18.9 m/s & 14.0 g & 326 & \textbf{0.388}\\
ThinSat (0.28 kg) & 18.8 m/s & 13.9 g & 123 & 1.029\\
PocketQube 3P (0.75 kg) & 18.4 m/s & 13.3 g & 108 & 1.172\\
TubeSat (0.75 kg) & 18.4 m/s & 13.3 g & 41 & 3.088\\
1U (1.33 kg) & 17.9 m/s & 12.6 g & 40$^{\dagger}$ & 3.165$^{\dagger}$\\
3U (4 kg) & 16.0 m/s & 10.1 g & 12 & \textbf{10.550}\\
6U (8 kg) & 14.1 m/s & 7.8 g & 6 & 21.100\\
12U (12 kg) & 12.7 m/s & 6.3 g & 3 & 42.200\\
\bottomrule
\end{tabular}
\end{table}

\subsection{Payload Class and the Mass-per-Satellite Argument}\label{sec:family}
Table~\ref{tab:family} is read most usefully from its last column rather than its first. Exit velocity is nearly flat across the family, because the 9.445~kg sled is most of the moving mass: removing the payload entirely buys 19\% of velocity, so velocity is a property of the sled and the stroke and not of the customer. Shortening the magnet array does not recover it either, since array length sets thrust and sled mass together---a 150~mm array gives a 5.15~kg sled but a 4.65~N per kA/m thrust constant, and the 3U case falls to 12.9~m/s.

The column that does move is deployer mass per satellite: by a factor of 27 between the 3U case and PocketQube~1P, and by 109 across the full column. At 3U the machine spends \textbf{10.55~kg of deployer per customer}, which loses to a cold-gas propulsion module delivering the same 16.0~m/s at 0.5--1.2~kg by a factor of between nine and twenty-one---12.4 against the 0.85~kg mid-class figure. At PocketQube~1P it spends \textbf{0.388~kg} and wins by 1.3 to 3.1. The comparison inverts on payload class, and on no machine parameter at all: not the thrust constant, not the stroke, not the sheet current. It inverts less decisively than it did: the figures published until 2026-08-20 were 7.04 and 0.24~kg, and the enclosure buildup that replaced an 8.00~kg packaging placeholder with 50.04~kg of derived line items moved both.

Three qualifications belong with those counts rather than beneath them. First, they are volumetric. The packing efficiency is calibrated against the one configuration that has been laid out in CAD---the 3U case, where a raw volume ratio predicts 21 and the magazine holds 12---and the resulting 56\% is then applied to classes for which no cassette exists. Second, the feed engages the CubeSat Design Specification corner-rail interface at the cradle, the escapement and the retention gate; PocketQubes, ThinSats and TubeSats do not have that interface, so a smaller class needs its own cassette, cradle and gate, which is mechanical design rather than a parameter change. Third, hundreds of satellites per load is a different machine from twelve: the campaign thermal case, the bank recharge duty and the escapement cycle life were all sized for twelve shots, and the bank is already the binding constraint at that number (Sec.~\ref{sec:lim}). What Table~\ref{tab:family} establishes is that payload class dominates the economic argument, not that a small-payload variant has been designed.

The comparison the 3U column loses most clearly is against the incumbent it was meant to match. A canisterised spring dispenser occupies roughly 6~kg per 3U slot, and an acceptance band written before the comparison script existed asked for parity within 15\%. The modeled ratio is \textbf{1.758}: this deployer is 76\% heavier per satellite than the hardware it would displace, and the band fails. It failed on a change to this work rather than to the comparator---a packaging rollup that had carried an 8.00~kg placeholder was replaced by 50.04~kg of derived line items, and parity did not survive it. The project's own kill criterion on mass per satellite, fixed at an estimated 2~kg, is crossed by \textbf{5.3$\times$}. No enclosure change reaches parity: the lightest alternative structure costed, a honeycomb sandwich, would give 8.87~kg per satellite and a ratio of 1.48. The route that moves this criterion is a smaller payload class, which is what the left of Table~\ref{tab:family} prices and what Sec.~\ref{sec:lim} records has not been designed.

It is not for want of looking. Every kilogram of the dry mass was attributed to the requirement that causes it---six requirements, from \emph{the satellite is unmodified} to \emph{twelve satellites share one drive}---and each of the 64 subsets was then deleted in turn to find the lightest machine any combination of relaxations could reach (Fig.~\ref{fig:ledger}). Three of the six carry no mass on their own. The best corner deletes both of the two that do, giving up the reusable mover and the requirement that the energy arrive during the shot, and it removes \textbf{37.89~kg, or 29.90\%}. \textbf{88.67~kg survives every deletion in all 64 corners}---70.06\% of dry mass, \textbf{7.39~kg per satellite against a 2~kg criterion}. Deleting requirements does not close it; only carrying more, smaller satellites does. The ledger is an attribution and an upper bound on what relaxation buys, not a sizing model, and it does not claim the surviving mass is irreducible by better design.

\begin{figure*}[t]
\centering
\caption{Constraint ledger: dry mass attributed to the requirement causing it, and the floor reached by deleting requirements in all 64 combinations. The floor is 88.67~kg, 70.06\% of the 126.56~kg rollup.}
\label{fig:ledger}
\end{figure*}

The architecture does not meet the spring-dispenser mass parity criterion. A separate earlier claim that waiting between releases gives satellites a persistent phase offset at zero relative velocity is also withdrawn: co-orbital zero-impulse releases from an unchanged host share the same state at a common epoch, as Sec.~\ref{sec:astro} explains. The contribution evaluated here is a modelled, commanded per-satellite orbital impulse without modifying the satellite, at a design acceleration of 10.1~$g$. Payload structural compatibility remains unverified; its qualified load environment and a host integration review are required. The modelled deployer costs 1.758 times the mass per satellite of the spring comparator.

\subsection{Astrodynamic Utility}\label{sec:astro}
A prograde ejection raises apogee while leaving perigee at the deployment altitude, so the correct claim is a longer-lived ellipse. At 450~km with ballistic coefficient 61~kg/m$^2$, an assumed 16.0~m/s impulse gives a modeled lifetime multiplier of \textbf{1.60} at mean solar activity (base lifetimes 0.52--2.61~yr across the activity range; Figs.~\ref{fig:life} and \ref{fig:uq}).

An earlier version of this work claimed the multiplier was invariant to two decimal places across ballistic coefficients of 40--90~kg/m$^2$ and across a fivefold density range, and offered that invariance as the result the analysis could defend. That claim does not survive an independent propagator. Run headless against MSISE90 with 20$\times$20 gravity, lunisolar third bodies and solar radiation pressure, GMAT R2022a reproduces the multiplier at mean and high activity but returns 2.07 at low activity, a spread of 18\% against a 5\% acceptance band fixed before the run. The reason is a defect in how the sweep was posed rather than in the arithmetic: the model represents solar activity as a uniform multiplicative scale on density, and ballistic coefficient enters the drag term in the same multiplicative slot, so both sweeps divide the two lifetimes being compared by the same factor. Their ratio cannot move, whatever the atmosphere does. A real atmosphere changes the \emph{shape} of the density--altitude profile with activity, the boosted orbit's apogee samples that profile some 37~km higher than the baseline's, and the ratio then does move. The multiplier is therefore quoted here at a stated activity level, and no invariance is claimed.

Differential ejection velocities put adjacent satellites on different periods: splits of 2, 5, and 10~m/s reach 30$^\circ$ spacing in \textbf{6.9, 2.8, and 1.4 days}. Under identical density and geometry assumptions, differential drag between 3:1 area configurations achieves the same spacing in \textbf{25.0 days} (Fig.~\ref{fig:dragvs}), consistent with flown drag-phasing campaigns operating over weeks to months \cite{foster}.

A common-epoch comparison must account for the actual state imparted at release. In a two-body reference case, a satellite released with zero relative velocity from an unchanged host follows the host orbit. A second identical release later follows that same trajectory; at any common time the two satellites are co-located. The host's angular travel between release events is not persistent separation between the satellites. The 1200~s inter-shot cadence is therefore a thermal and recharge assumption, not a phasing result. Conventional spring impulses, host manoeuvres and subsequent differential drift remain valid comparators and must be included in any mission-level phasing trade.

A differential deployment impulse can change orbital period and create a growing phase separation, as the preceding model shows. It does not establish a permanent fixed angular offset without later control or drift management. The differential-drag comparison in Fig.~\ref{fig:dragvs} is conditional on the stated area and atmosphere assumptions. A matched comparison of commanded electromagnetic shots, spring deployment, host manoeuvres and drag is still needed before asserting a phasing advantage.

A historical-input cross-check independently propagates the Cartesian post-release state for two orbital periods and recovers a 28.800775~km semi-major-axis rise at 16.029~m/s. The 0.02~m solver/identity band passes. This verifies instantaneous two-body geometry, not the 1.60 lifetime multiplier, host campaign or launcher performance. The method and exact inputs are archived in the local validation record.

The Gen5 model instead evaluates a commanded change in the deployed satellite's orbit. Its 16.0~m/s prograde shot predicts a 28.8~km semi-major-axis increase and a 1.60 lifetime multiplier at the stated mean-activity condition. A 2.5~m/s spring is also an orbital impulse and produces an 8.2\% modelled lifetime extension under the same setup. Release timing without an impulse changes neither orbit; a manoeuvring host can change the initial orbit of later releases. These are different mission cases, and the quoted Gen5 benefit is model output rather than demonstrated performance.

\begin{figure}[t]
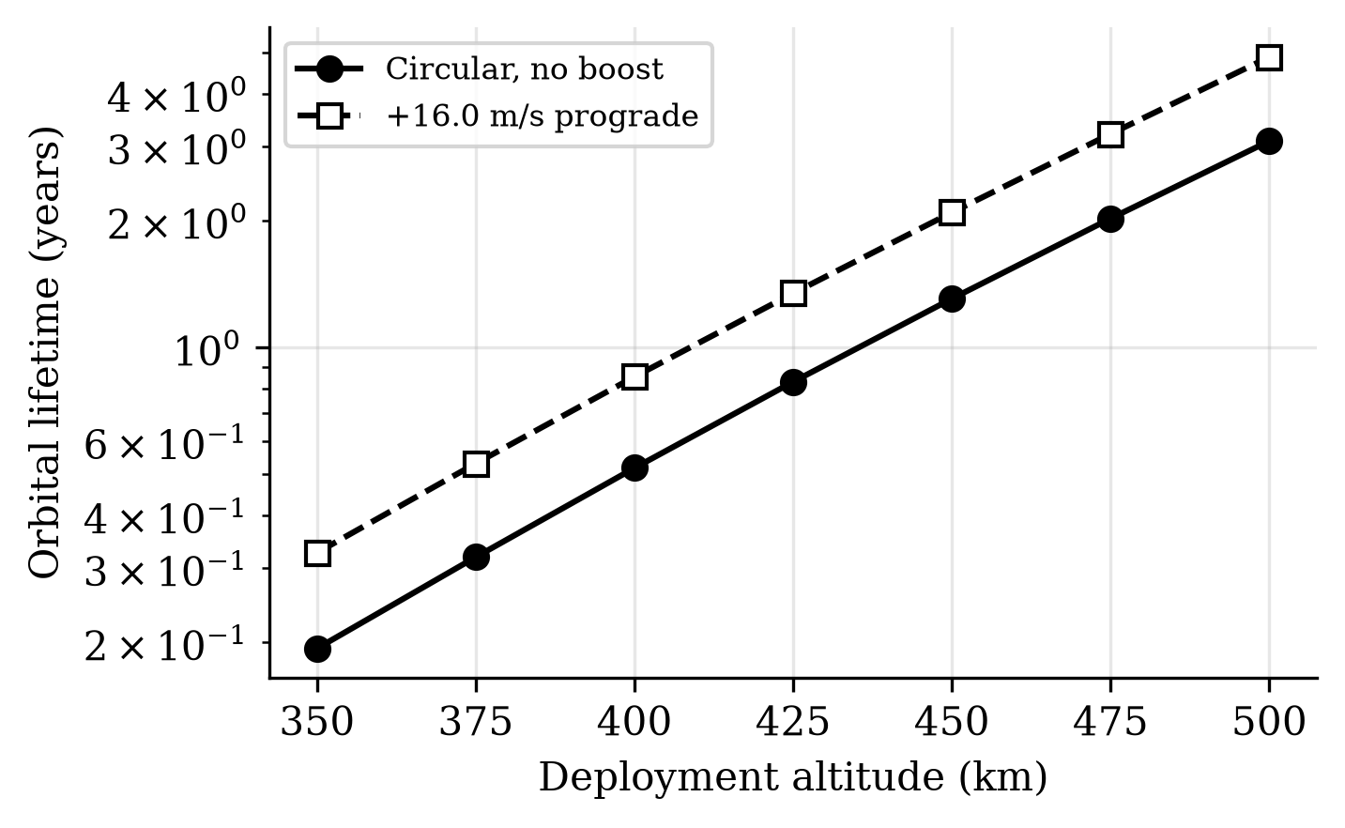
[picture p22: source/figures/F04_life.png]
\centering
\caption{Orbital lifetime vs deployment altitude (BC = 61 kg/m$^2$, mean activity).}
\label{fig:life}
\end{figure}

\begin{figure}[t]
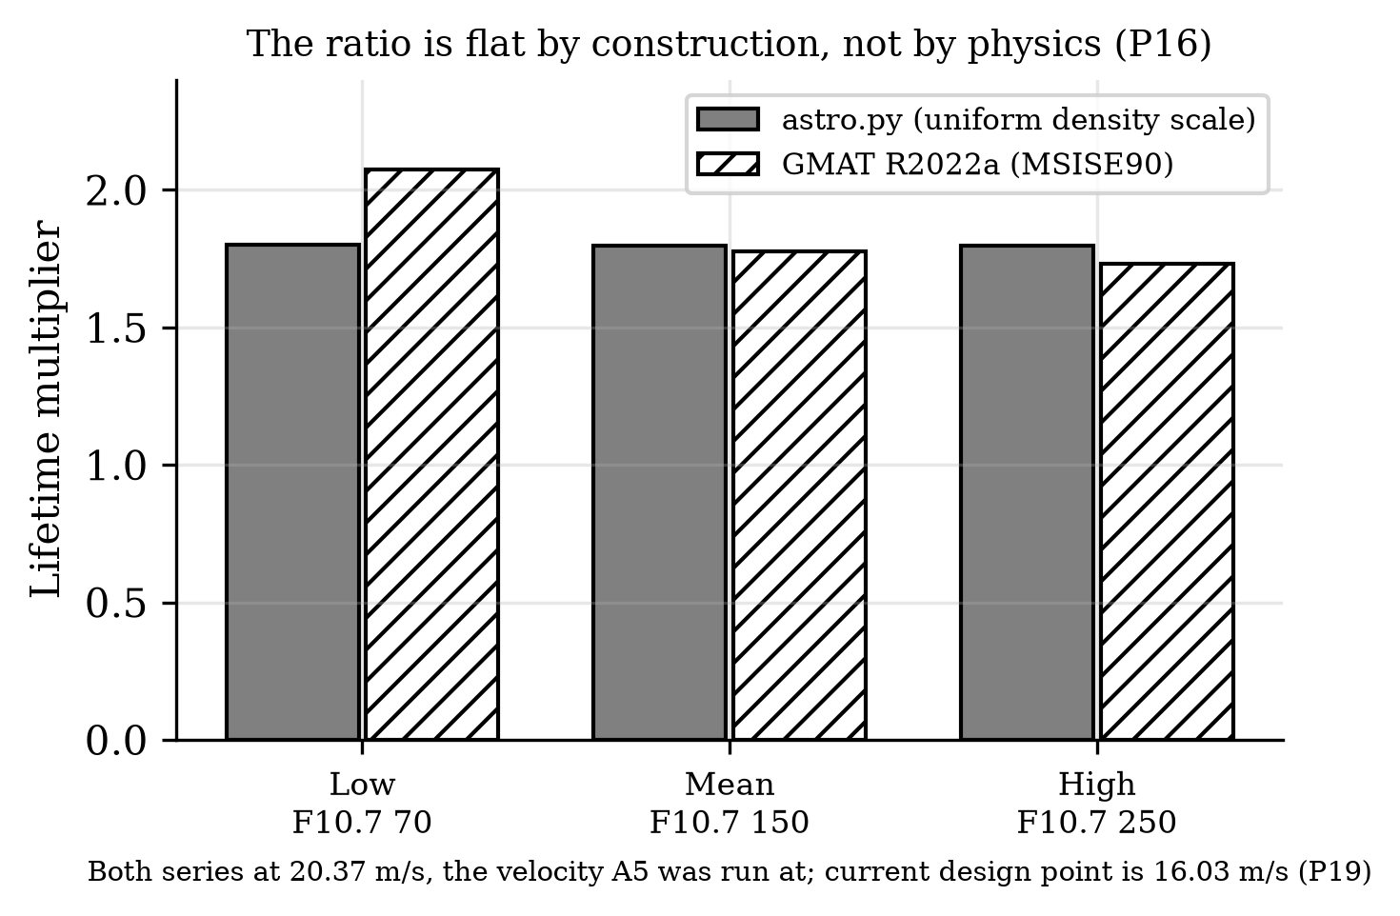
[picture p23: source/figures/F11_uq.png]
\centering
\caption{Solar-activity sweep against GMAT. The static-atmosphere model returns a flat ratio by construction, not by physics; an independent propagator does not.}
\label{fig:uq}
\end{figure}

\begin{figure}[t]
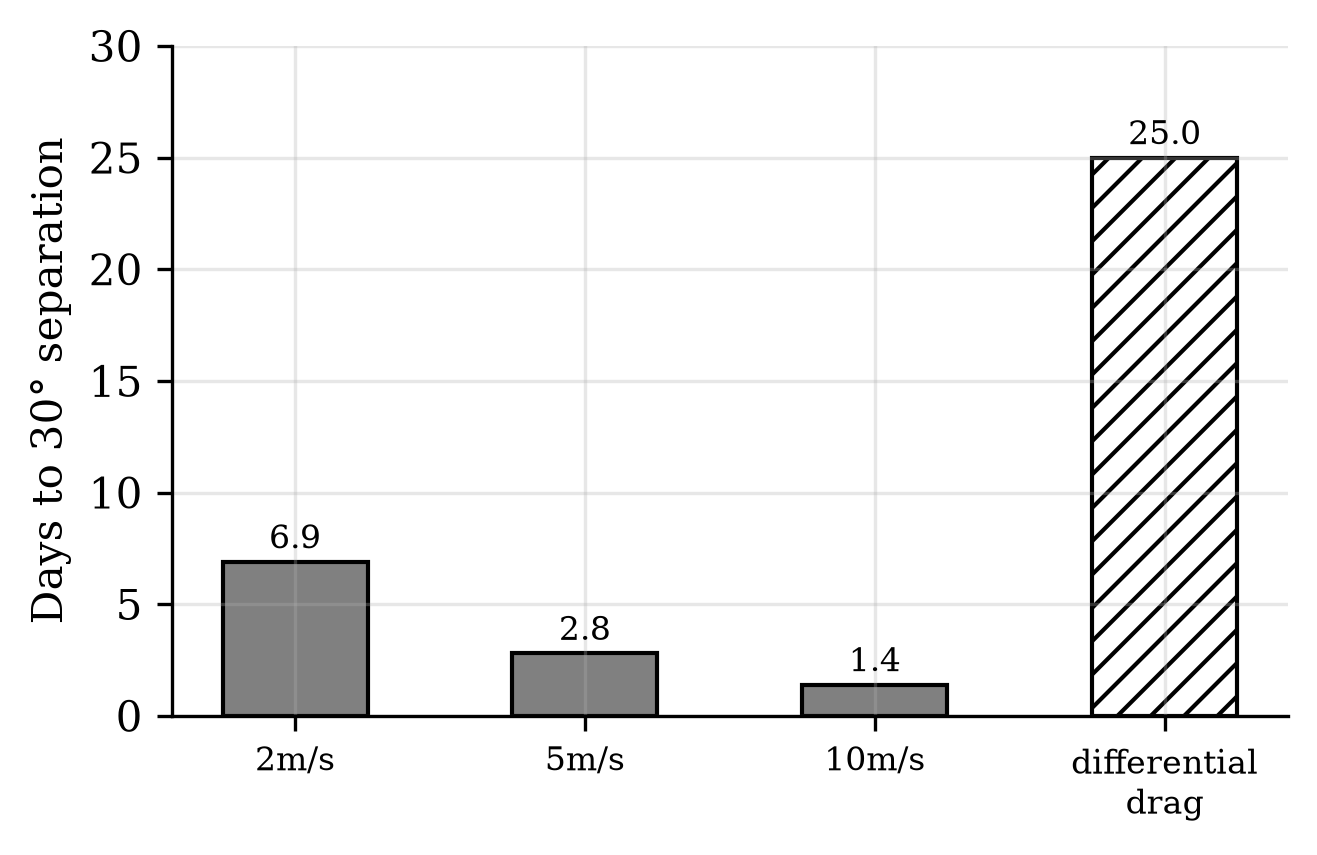
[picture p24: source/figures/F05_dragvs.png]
\centering
\caption{Modelled velocity-split phasing versus differential drag under identical assumptions. The figure does not include spring impulses, host manoeuvres or a complete mission-level comparator.}
\label{fig:dragvs}
\end{figure}

\subsection{Deployment Safety}
Every prograde shot leaves an ellipse whose perigee sits at the firing altitude, so the fleet re-crosses the stage's orbit by construction, and the along-track phase between a deployed satellite and the stage realigns on a period of \textbf{10.3 days} for the assumed historical velocity (Fig.~\ref{fig:conj}). The closest approach reached within a 30-day screening window is deliberately \emph{not} quoted here as a safety figure: because both bodies re-cross the same altitude, that minimum is fixed by the exact along-track phase at crossing, which is acutely sensitive to ejection velocity---in the model a $\pm2.5\%$ change about that assumed point sweeps the 30-day minimum by more than an order of magnitude. It is a near-resonant sample of the beat geometry, not a design property. Two statements survive that sensitivity and carry the safety argument. First, per-shot collision-avoidance (COLA) screening is \textbf{mandatory} for every ejection, because the approach geometry cannot be certified from the nominal velocity alone. Second, disposing of the host stage before the first \mbox{10.3-day} realignment---routine for a restartable stage---removes the recurring close-approach mechanism at its source, before the fleet can return to the stage's along-track position. Per-shot conjunction products remain a mission-operations deliverable.

\begin{figure}[t]
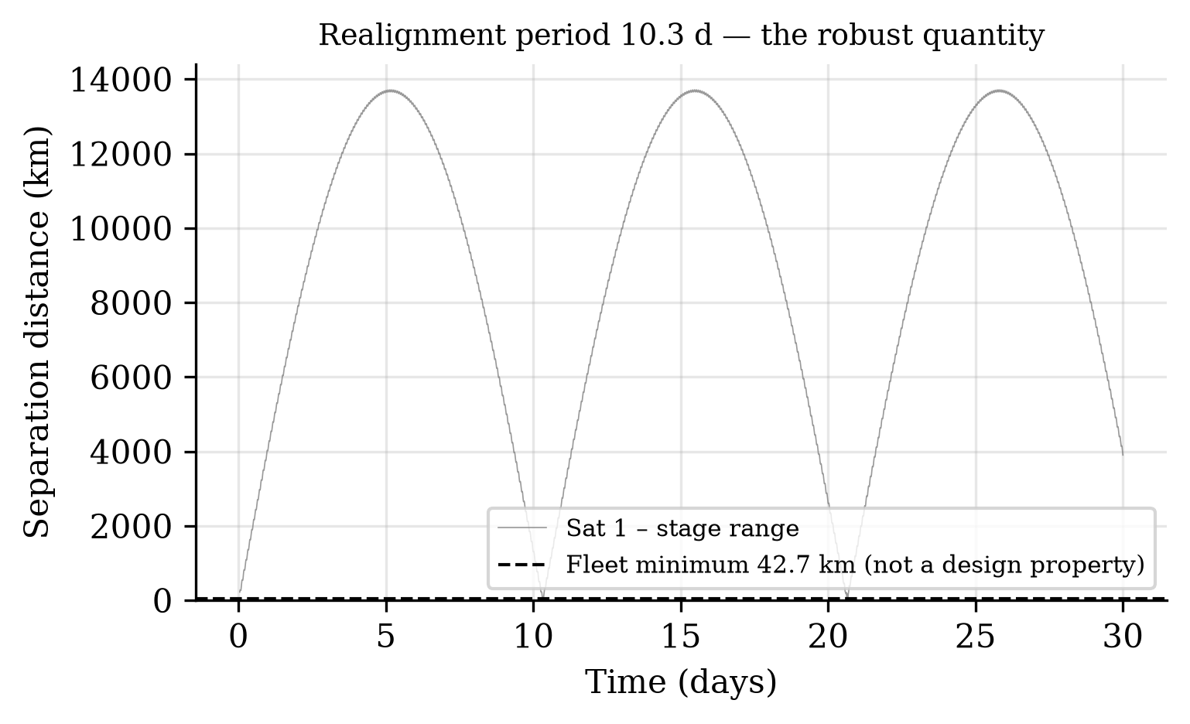
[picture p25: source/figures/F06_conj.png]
\centering
\caption{Satellite--stage range over 30 days, staggered firing at the rated velocity.}
\label{fig:conj}
\end{figure}

\subsection{Error, Tip-Off, and Mass}
The 0.0274~m/s dispersion maps to \textbf{$\pm$0.10~km apogee placement} at 450~km: sub-kilometre deterministic insertion for a satellite with no propulsion. Tip-off is modelled rather than bounded, and the risk is not where the analytic budget put it. Release occurs 200~mm---12.2~ms---into the coast-and-trim zone with commanded force already at zero, so at the residual latch and friction load the mechanism tolerates roughly 250~$\mu$s of asymmetry and still lands two orders of magnitude inside the 2~deg/s comparator. What is not benign is the start of the stroke: the payload centre of mass sits 70~mm off the thrust line, the 413~N push therefore applies a 28.9~N$\cdot$m moment, and the payload accelerates across its cradle clearance at 688~rad/s$^2$, arriving at 36--231~deg/s depending on fit---18 to 115 times the comparator. Whether that impact has damped out by release depends on a restitution model this study does not have, so tip-off is stated as a requirement on a cradle preload exceeding the 85~N couple reaction and on a release residual below about 1~N, against a release mechanism that remains undefined (Fig.~\ref{fig:tipoff}). Recoil per shot is the satellite's momentum only, \textbf{64.1~N$\cdot$s}, the sled's share returning through the brake. The solid model closes dry mass at \textbf{126.6~kg} (loaded 174.6~kg, centre of gravity 0.46~m from the breech), with the ironless stator at 7.3~kg of copper and formers; the system uses roughly a third of an ESPA Grande \emph{mass} allocation. It does not currently fit the corresponding envelope: the closed CAD assembly spans 1839~mm along the track against the roughly 1270~mm of that class, because the arrest brake sits beyond the release point and the enclosure must span it. The third of those routes is the one taken: the target host class is a restartable upper stage, kick stage, or hosted orbital platform, and ESPA-Grande port compliance is not a requirement of this design. That is a re-scope, not a fix, and its cost is stated rather than absorbed. Shortening the track to 1270~mm would leave a 731~mm acceleration zone and, since velocity goes as $\sqrt{L}$, would cut ejection from 16.0 to 12.0~m/s---a 25\% loss in the quantity every performance claim here rests on. The re-scope avoids that and gives up the ESPA-Grande port population in exchange. It also leaves the packaging question unanswerable for now rather than answered: no accommodation envelope for the target host class is public, so the 1839~mm length cannot presently be shown to fit anything, and obtaining that envelope is part of the same single data exchange Sec.~\ref{sec:host} identifies. This is an open item, and the honest description of it is that a measured failure against a published limit has become an unmeasured unknown against an undisclosed one.

\begin{figure}[t]
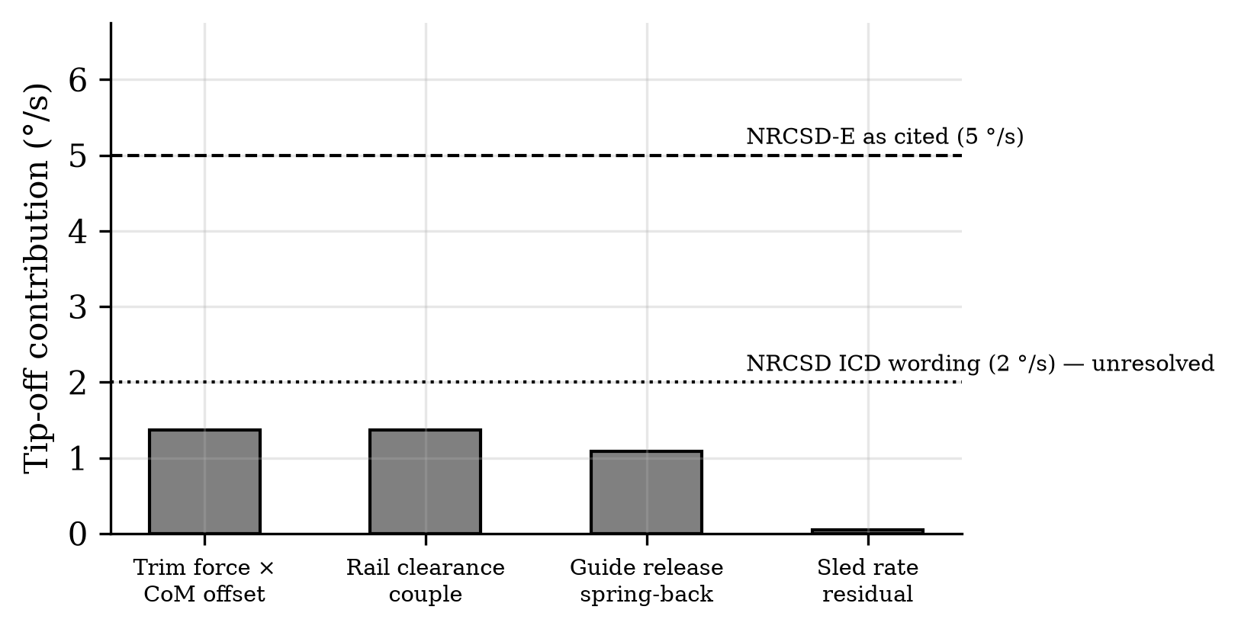
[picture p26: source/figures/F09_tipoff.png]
\centering
\caption{Tip-off error budget against deployer requirement classes.}
\label{fig:tipoff}
\end{figure}

\begin{figure}[t]
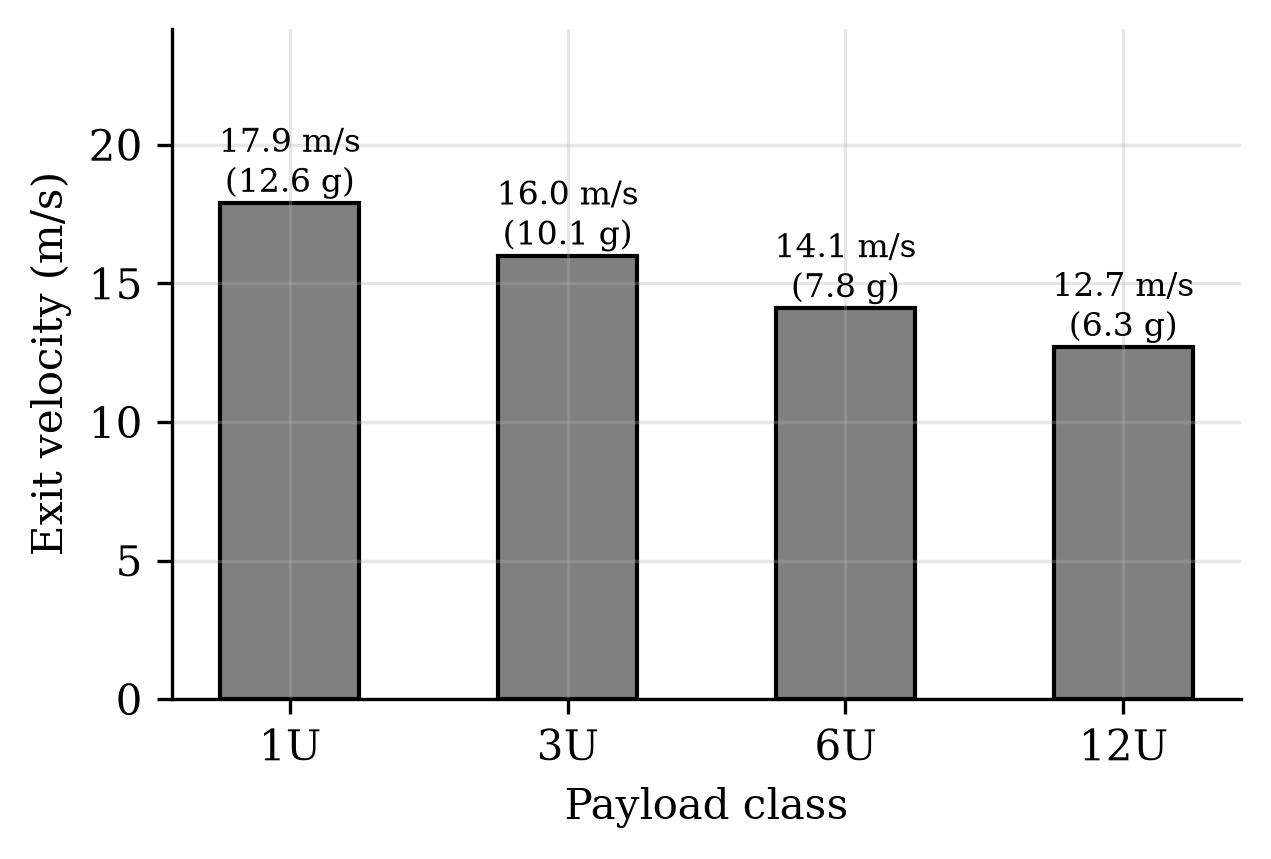
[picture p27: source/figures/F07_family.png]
\centering
\caption{Payload family: force-limited above 1U; velocity, not safety, is traded. $^{\dagger}$Counts are \emph{volumetric}, calibrated so the 3U case returns the twelve the machine is laid out for. A subsequent fixed-cell design study replaces them where a cell geometry actually exists: 1U gives \textbf{36 per load at 2.125~kg}, not 40 at 1.92, because three 100~mm units plus two dividers leave 37.5~mm of a 340.5~mm cell unusable, and \textbf{ThinSat and 12U are refused outright} because two of their dimensions exceed the 100~mm cell section. The binding constraint is the 166~mm cassette width.}
\label{fig:family}
\end{figure}

\section{Generalized Host Integration}\label{sec:host}
\subsection{Interface Requirements for Any Host}
The reference host analysis assumes a mechanical mount, 150--300~W recharge allocation or an equivalent battery, an attitude reference and control authority for shot transients, and a compliant disposal plan. These are requirements to negotiate, not verified provisions of any particular stage. The quoted full-manifest momentum and propellant estimates are idealized budget calculations; actual correction, attitude recovery and disposal cost depend on host dynamics, thruster performance and the delivery sequence. Table~\ref{tab:recoil} varies the assumed host mass to show the translation sensitivity. A free-flyer variant would need its own GNC and is outside this Gen5 study.

\begin{table}[t]
\caption{Per-shot recoil (64.1 N$\cdot$s) versus host class}
\label{tab:recoil}
\centering\footnotesize
\begin{tabular}{lcc}
\toprule
Host class & $\Delta V$ per shot & 12-shot total\\
\midrule
200 kg free-flyer & 328 mm/s & 3.93 m/s\\
300 kg kick stage & 219 mm/s & 2.62 m/s\\
600 kg kick stage & 109 mm/s & 1.31 m/s\\
900 kg (PS4 class) & 72.8 mm/s & 0.87 m/s\\
420 t (station class) & 0.2 mm/s & 2.3 mm/s\\
\bottomrule
\end{tabular}
\end{table}

\subsection{Worked Host Examples}
ISRO's POEM missions demonstrate that a spent stage can support hosted experiments and controlled disposal \cite{poem3,poem4}. Published Skyroot descriptions indicate interest in restartable orbital operations \cite{oam,spacenews}. These are contextual examples only. No host has supplied an interface control document, confirmed available mass/power/attitude margins, accepted a magnetic payload environment or approved VOLLEY accommodation. A real host trade must obtain the stage mass and inertia, permitted envelope, bolt pattern, power/command provisions, recoil and pointing limits, disposal requirements and provider safety process. The parametric recoil cases in Table~\ref{tab:recoil} must not be read as compatibility findings.

\subsection{Integration Interfaces}
A candidate integration would need a provider-approved mechanical interface, an electrical recharge and inhibit interface, an authenticated command/telemetry interface, and verified attitude, thermal, magnetic, debris and disposal constraints. The current CAD includes only a reference ring shape and bracket assumption; it does not establish ESPA or ESPA-Grande accommodation. An assumed 150--300~W recharge allocation, state-vector input and shot authorization are model inputs rather than approved host services. The deployer would command the modeled release only inside a host-authorized window, and the host would retain attitude and disposal authority. Payload-side exposure also matters: the modeled permanent-magnet field at the near payload face exceeds a representative magnetometer full scale, so compatibility requires a named payload and an explicit exclusion, standoff or shielding decision (Sec.~\ref{sec:env}).

A multi-shell mission could combine host manoeuvres and deployer release impulses, but its value must be calculated against spring release, differential drag, onboard propulsion and orbital transport with the same manifest and deadlines. A prior claim that release timing alone created persistent phase has been withdrawn. No complete twelve-payload campaign closes in the six sampled finite-burn cases, so this paper does not claim a delivered four-shell or twelve-target service.

\subsection{Position in the Deployment Landscape}
Spring deployers provide a mature reference for low-velocity separation; a host manoeuvre, differential drag or an orbital transfer service can add mission-level placement. VOLLEY is an unbuilt computational candidate for commanded release. Table~\ref{tab:tier} contrasts the studied functions and flags where a common-mission comparison or supplier-backed mass is absent. The approximate 6~kg spring canister used elsewhere in this paper implies about 72~kg for twelve 3U units, while the modeled Gen5 dry mass is 126.6~kg. No gap in the commercial market is established by this technical comparison.

\begin{table}[t]
\caption{Service tiers for small-satellite orbit placement. VOLLEY's system mass is 126.6~kg dry and 174.6~kg loaded with twelve 3U satellites}
\label{tab:tier}
\resizebox{\columnwidth}{!}{%
\centering\scriptsize\setlength{\tabcolsep}{2.5pt}
\begin{tabular}{lccc}
\toprule
Attribute & Spring deployer & VOLLEY (this work) & Transfer vehicle\\
\midrule
Release / transfer & low-m/s device-dependent & 16.029 m/s model point & mission-dependent\\
State targeting & impulse and host-dependent & 0.0274 m/s simulated $3\sigma$ & service-dependent\\
Payload interface & qualified per device & compatibility unverified & service-dependent\\
System mass, 12$\times$3U & $\sim$72 kg comparator & 126.6 kg dry model & quotation needed\\
Plane/LTAN change & host/drag-dependent & not demonstrated & service-dependent\\
Evidence status & flight heritage & computational study & provider-specific\\
\bottomrule
\end{tabular}}
\end{table}

\subsection{Demonstration Path}
\subsection{What Air Costs a Ground Test}\label{sec:airdrag}
The machine operates in vacuum and every velocity above is computed with no aerodynamic term, but the full-scale demonstration fires a mass simulator down the track in a laboratory at sea level, so the comparison that test exists to make is between a measured velocity and a computed one that omits the air. A steady RANS solution ($k$-$\omega$ SST) around the sled and payload \emph{as generated}, meshed directly from the CAD surfaces rather than from an idealised body, gives a drag coefficient of \textbf{0.52} on a 201.6~cm$^2$ projected frontal area at $Re = 7.0\times10^5$, i.e. 1.73~N at exit velocity. Because the profile is position-scheduled, $v^2$ rises linearly with distance and so does the drag, making the work over the 1.30~m acceleration zone 1.13~J and the exit-velocity deficit \textbf{5.1~mm/s}, or 0.031~\% (Fig.~\ref{fig:airdrag}).

That figure is small against the design point and \emph{not} small against the quantity a ground test resolves: it is \textbf{19~\% of the 3$\sigma$ closed-loop dispersion}. An atmospheric ground test can be considered for initial velocity measurements, but its air-load correction and uncertainty must be reported; vacuum and thermal testing remain separate qualification questions. The distinction depends on how the test is run: open-loop, the deficit appears as 5.1~mm/s of velocity; closed-loop, the servo nulls it and it appears instead as 1.73~N of additional commanded force, 0.125~\% of the shot.

\begin{figure}[t]
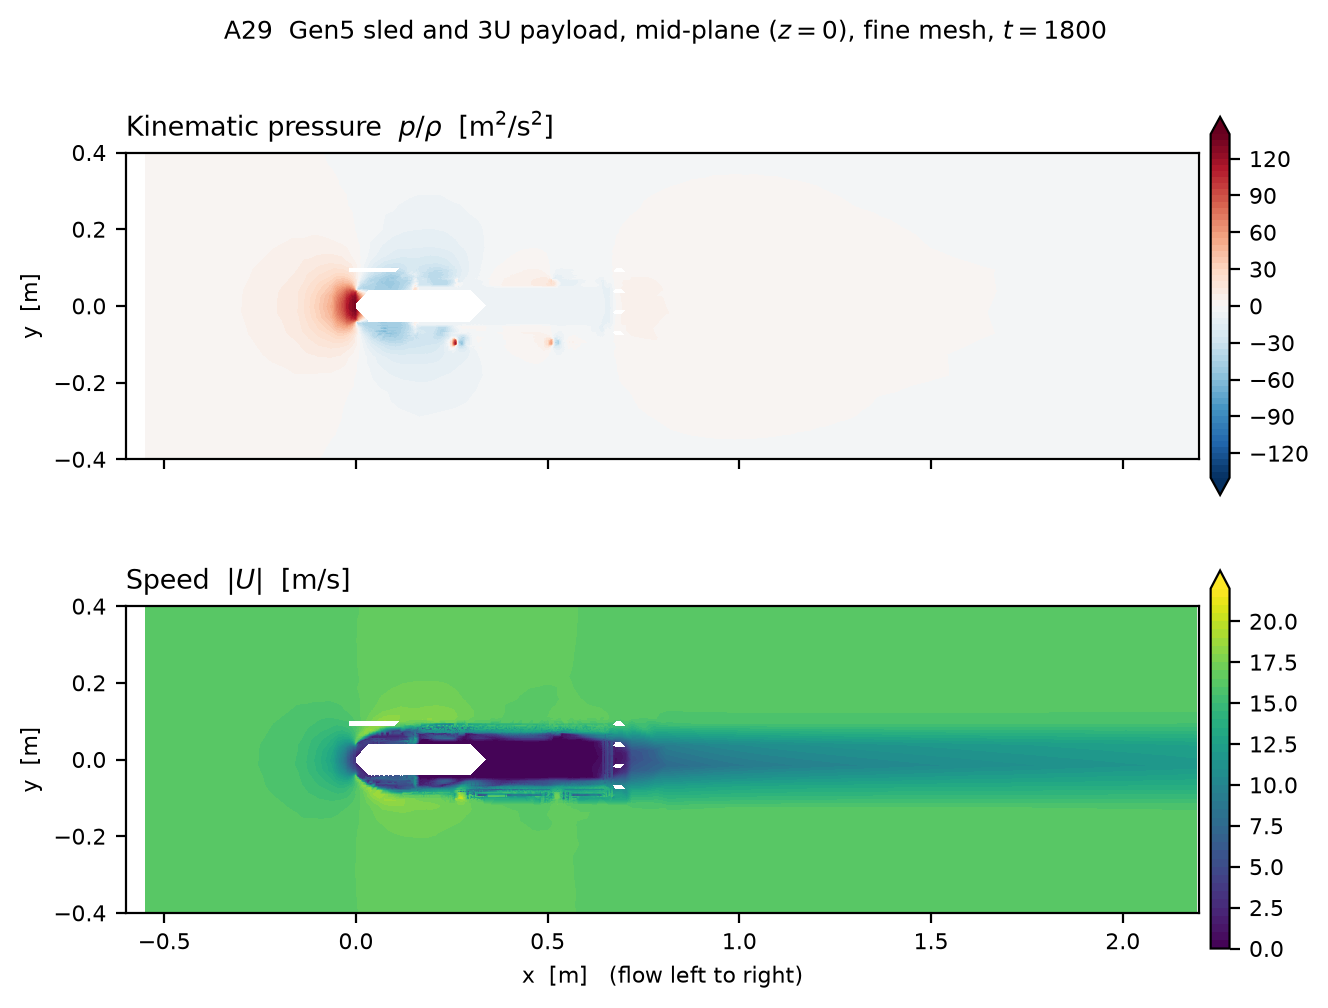
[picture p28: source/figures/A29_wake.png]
\centering
\caption{Mid-plane slice ($z=0$) of the converged fine-mesh solution: kinematic pressure above, speed below, flow left to right. Stagnation on the forward face, separation at the shoulders, and a wake that has not recovered by $x=2.2$~m. The pressure term shown here is integrated directly from the solved field; \textbf{the viscous term is not solved} and is bounded by a turbulent flat-plate correlation over the meshed wetted area, as the text states.}
\label{fig:wake}
\end{figure}

\begin{figure*}[t]
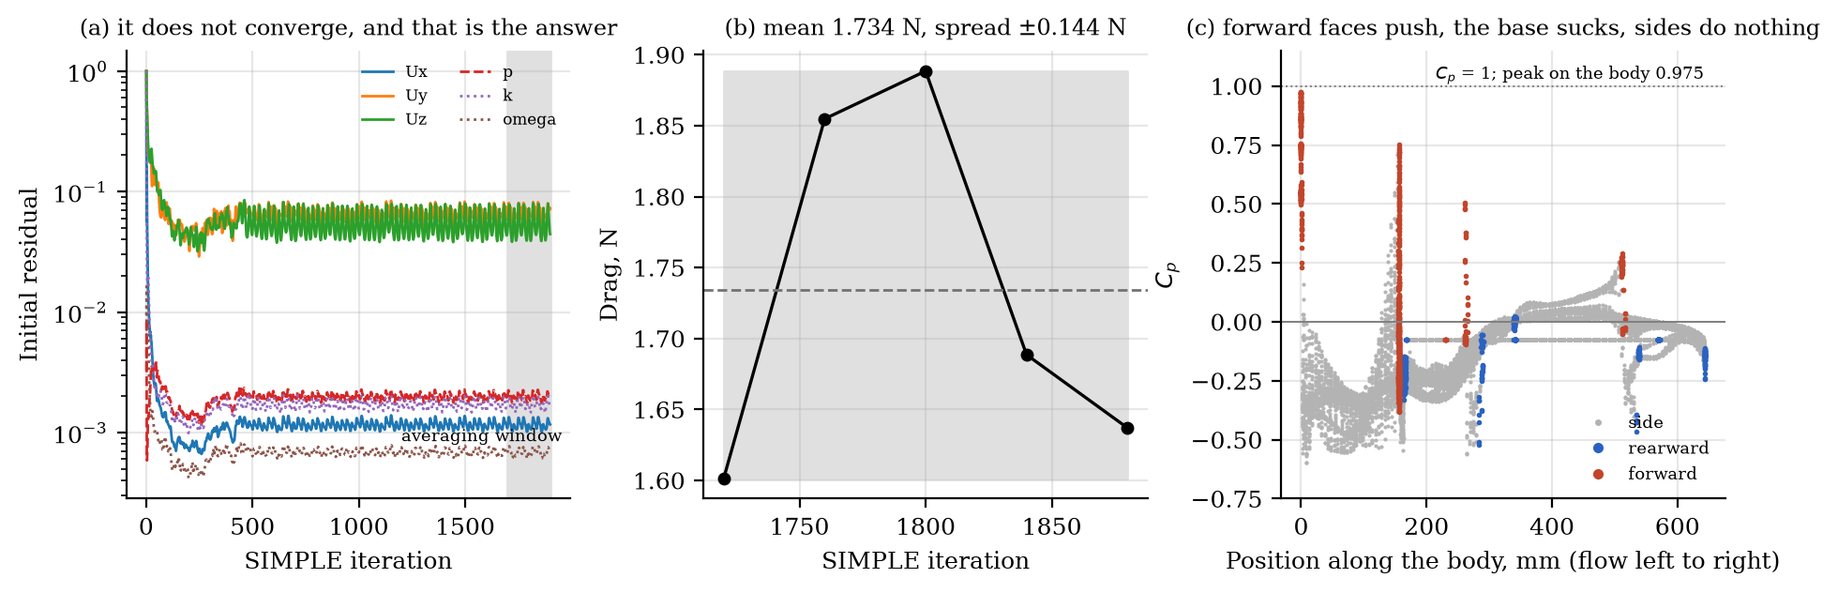
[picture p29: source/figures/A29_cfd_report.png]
\centering
\caption{Force history and mesh convergence for the same case. The force is a mean over a window of iterations quoted with its spread, $1.734 \pm 0.144$~N, because a steady solver on a massively separated wake plateaus rather than converges; $6.3\times$ the cells moves the answer by 4.86~\%.}
\label{fig:cfdconv}
\end{figure*}

Two properties of the solution are reported rather than presented as convergence. The velocity residuals fall three orders and then plateau near $5\times10^{-2}$, which is what a steady solver does on a massively separated wake, so the force is a mean over a window of iterations quoted with its spread, $1.734 \pm 0.144$~N. And the viscous contribution is a turbulent flat-plate bound over the meshed wetted area rather than a solved wall shear stress, 17.7~\% of the total; the pressure term, which dominates, is integrated directly from the solved field over the body surface. Adding the stator plates \emph{reduces} drag by 13~\% and halves the oscillation, the plate acting as a wake splitter rather than as a confining wall, so the free-stream figure quoted above is the conservative one.

\begin{figure}[t]
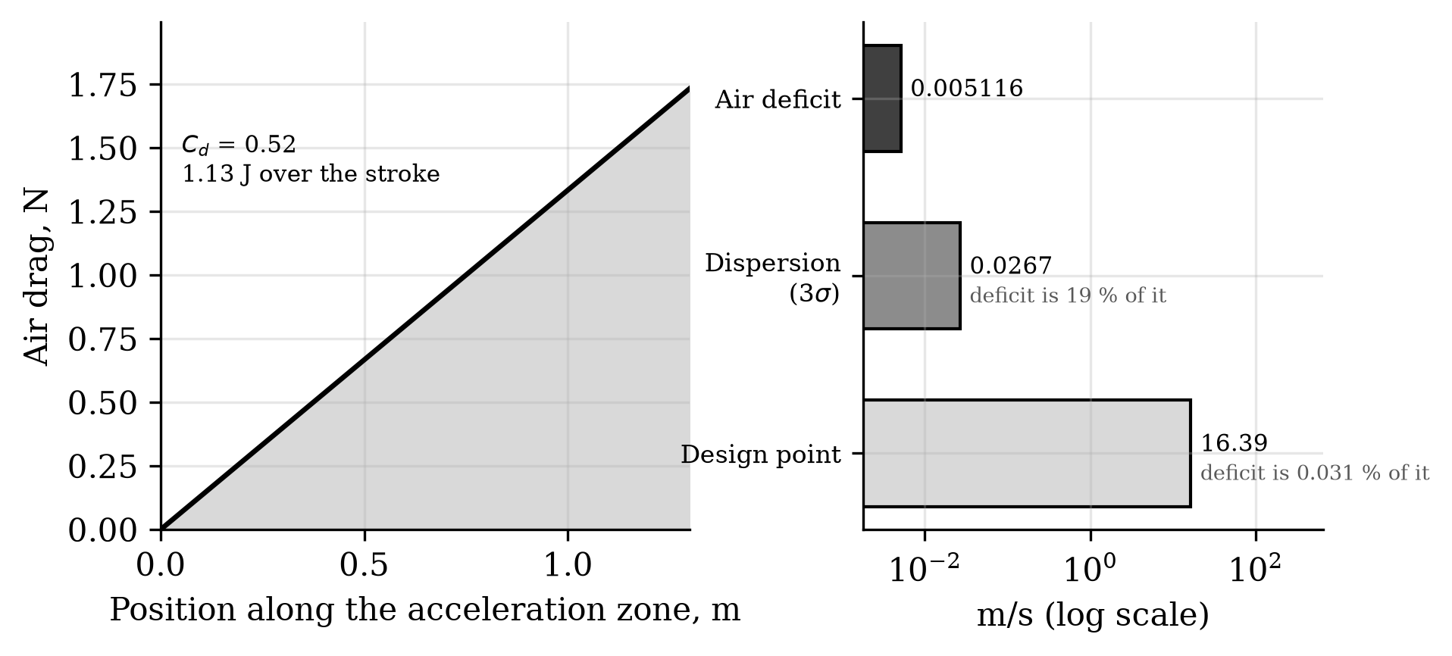
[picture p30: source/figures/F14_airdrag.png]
\centering
\caption{Air drag along the acceleration zone, and the resulting exit-velocity deficit set against the design point and against the dispersion a ground test exists to resolve.}
\label{fig:airdrag}
\end{figure}

A future instrumented ground article could measure sled and payload velocity, feed forces, tip-off, brake temperature and cycle reliability against predeclared bands. Its length, containment, cost and site approvals require engineering and a quotation; this study supplies neither. A captive hosted test would require a named platform, provider interface and safety approval even if the payload were never released.

\section{Sensitivity and Uncertainty}\label{sec:sens}
Because several inputs carry manufacturing or environmental spread, the historical shot point is bracketed by a first-order sensitivity analysis (Table~\ref{tab:sens}). Each coefficient is the local partial derivative of exit velocity or thrust with respect to the listed variable, evaluated at that historical point. The dominant contributors are payload mass and magnet remanence; the velocity model is mild in all of them, and the closed-loop servo further collapses the delivered dispersion to 0.0274~m/s (Sec.~V-A) because it commands current against measured position rather than trusting the plant. Root-sum-square combination of the manufacturing terms (magnet grade $\pm2\%$, gap $\pm0.05$~mm, resistance $\pm5\%$, ESR $\pm20\%$) gives an open-loop velocity spread of $\pm2.1\%$, consistent with the Monte Carlo of Fig.~\ref{fig:mc}. Environmental terms are handled by rating margin: the N45SH remanence temperature coefficient of $-0.11\%$/K over a $\pm40$~K operating band moves the thrust constant by $\mp4.4\%$, so the worst-case cold-to-hot requirement of 132~kA/m stays inside the 140~kA/m current rating without re-tuning. Atmospheric and solar-activity spread do not affect the machine and enter only through orbital lifetime, where Sec.~V-B records that the sweep previously offered as evidence of invariance could not, by construction, have detected a change.

\begin{table}[t]
\caption{First-order sensitivities of the historical shot model}
\label{tab:sens}
\centering\footnotesize
\begin{tabular}{lcc}
\toprule
Variable & Affects & Sensitivity\\
\midrule
Payload mass & $v$ & $-\tfrac{1}{2}$ (\%/\% of $m_{\mathrm{tot}}$)\\
Magnet remanence $B_r$ & $F,v$ & $+1.0,\ +0.5$ \%/\%\\
Current density & $F,v$ & $+1.0,\ +0.5$ \%/\%\\
Winding resistance & $\eta$ & $-0.15$ \%/\%\\
Capacitor ESR & sag & $+0.04$ V/m$\Omega$\\
Gap asymmetry & $K_t$ & $-13$ \%/mm\\
Sensor noise (8 mm/s) & dispersion & sets 3$\sigma$ floor\\
Temperature ($B_r$) & $K_t$ & $-0.11$ \%/K\\
\bottomrule
\end{tabular}
\end{table}

\section{Mechanical Analysis}\label{sec:mech}
The structural load path is sized to the two governing cases: launch vibration during ascent and the arrest impulse during operation. Fastener and pin margins are quoted on ultimate strength at a 1.4 design factor per common launch-hardware practice, consistent with the qualification philosophy of GEVS \cite{gevs} and ECSS structural standards \cite{ecss}.

\emph{Track stiffness.} The dominant flight requirement is a first natural frequency above the launch-vehicle primary band, conventionally 70--100~Hz for secondary structure. Modeling the twin-longeron track as a uniform beam carrying the 20~kg stator distributed mass, the fundamental is $f_1=(\lambda_1^2/2\pi L^2)\sqrt{EI/\mu}$ with $EI$ from two 7075 box sections. A simply-supported idealization gives 48~Hz, but bracketing both ends into the ESPA ring (fixed-fixed) raises the first mode to 109~Hz, clearing the requirement; the design therefore specifies end-fixed mounting with an intermediate rib.

\emph{Inter-array attraction.} The two Halbach faces attract across the gap with a Maxwell stress $p=B^2/2\mu_0\approx120$~kPa at the 0.55~T mean working field, or 3.7~kN over the array footprint. Carried as a bending load into the titanium side plates, this produces 33~MPa against the 880~MPa Ti-6Al-4V yield, a margin above 20; the attraction is structurally minor and, being static, does not fatigue-cycle. The flat-plate expression overstates the force: a three-dimensional integration of the field gradient over the meshed blocks returns 2.69~kN, some 37\% lower, because the assumed 0.55~T is not the mean normal field over the separation plane. Jensen's inequality acts in the opposite direction and does not explain the overestimate. Extending the Maxwell-stress plane beyond the magnet footprint gives 2.680~kN, within 0.25\% of the 2.687~kN volume-force calculation; this is model-to-model agreement, not experimental validation. The earlier finite-element load remains conservative.

\emph{Arrest and roller loads.} At the 200~$g$ arrest cap the 9.445~kg sled develops 18.5~kN axially, reacted by the ring-spring stop; the pitch couple during braking loads the guide rollers to roughly 1.48~kN per pair. This is the load path most affected by adopting the CAD-derived sled mass---it very nearly doubles---and it is the one place where the heavier sled makes the machine harder rather than merely slower. Bearing selection at 1.48~kN per pair is within the rating of a 440C/Si$_3$N$_4$ hybrid of this size, but the reuse duty is not addressed here: the sled is braked twelve times per campaign in vacuum, and no lubrication or contact-life assessment has been performed. The abort latch, engaged only for a commanded abort, carries the 13.4~kg carriage at the abort deceleration, 0.42~kN, through dual A-286 pins at a margin above eight.

\emph{Fatigue and tolerance.} Operational cycling is benign: the magnet bond sees 0.12~MPa per shot against a 10~MPa allowable, far below any endurance concern over the few hundred shots of a service life. Positional accuracy is set by the winding-to-magnet gap, whose $-13\%$/mm thrust sensitivity dictates a $\pm0.05$~mm shim tolerance to hold thrust within $\pm0.65\%$; this is a standard precision-shim assembly, not a novel requirement.

\subsection{Architecture reliability, and the bar it sets}
A spring dispenser is twelve independent one-shot mechanisms in parallel: one failure costs one satellite. This design is one mechanism in series with itself, cycled twelve times. The sled, stator, converter, energy store, sequencer and brake serve every shot, and the escapement and retention gate cycle twelve times each, so a failure at shot $k$ forfeits shots $k$ through twelve. Enumerating the shot chain, \textbf{nine of thirteen elements forfeit the remaining manifest on a single failure, against zero for a spring dispenser}, and nine shared elements over twelve cycles is 108 opportunities to fail. This is structural and no component quality removes it.

What component quality does change is where the comparison lands. Writing $p$ for the probability that the shared chain survives one shot, expected delivery is $\sum_{k=1}^{12}p^k$, which departs from a spring's independent $12q$ quickly. Against a spring at $q=0.99$, matching on \emph{satellite count} requires $p=0.9985$, which is not a realistic target for a twelve-cycle electromechanical system without flight heritage. Matching on \emph{delivered orbital life} requires only $p=0.9347$, because each delivered satellite is worth 1.50 times a spring-deployed one. Expressed per element per cycle, the requirement is $r\geq0.99326$.

\textbf{That is the first quantitative reliability requirement this design has carried, and it is not yet met or measured}: no cycle-life test exists for the escapement, the gate or the sled. Two candidate mitigations are defined but are deliberately not credited above, because crediting them without analysis is the optimism the exercise exists to avoid. Retention gates are per cassette, so one gate fault forfeits six rather than twelve. And the winding is segmented: a dead segment is a length the sled coasts over rather than a stopped machine, so at four segments a failure downstream of the breech still exits at 14.19~m/s, 86.6\% of nominal. The exception is the breech segment itself, where no force acts on a stationary sled and the shot never starts, which makes duplicating or overlapping that one segment the cheapest available reliability action.

\section{Thermal Analysis}\label{sec:thermal}
The shot model assigns approximately 855~J to stator copper, 1162~J to sled braking, 93~J to the converter and 78~J to the bank ESR per rated cycle. Multiplying an assumed twelve-shot total of 26.6~kJ by a uniform 13.5~kJ/K structure thermal capacitance gives a 2.0~K \emph{bulk-average} rise; it says little about local peak temperatures. The corrected 0.344~kg fin mass gives a 9.0~K adiabatic rise per shot and a 108~K twelve-shot no-cooling bound. A transient conduction/radiation model has not established cooling between shots at the adopted 1200~s cadence. The 0.32~m$^2$ radiator estimate uses an assumed 130~W rejection case and is not a closed thermal design. Component survival temperatures, heater power and irreversible magnet loss require supplier data and orbit-specific hot/cold cases. The rated thermal claims remain model estimates, not environmental qualification.

\section{Power Electronics}\label{sec:pe}
The electrical architecture proposes a 96~V, thirty-two-cell pulse bank and a three-phase SiC inverter with position-synchronized control. The winding model predicts 19.7~$\mu$H, a 373~A peak phase current and 25.2~m$\Omega$ per phase at the historical modeled point; 320~A is the reported DC-link peak and is a different quantity. At the assumed 20--40~kHz switching range, the calculated current ripple and copper contribution are model outputs. Device ratings, switching overshoot, gate-drive loss, cell balancing, fault-clearing energy and flight derating have not been checked with a selected part list or a physical converter.

Current limiting, bus clamping, desaturation shutdown, balancing, bleed/passivation, segmentation, shielding and dual sensing are proposed controls. None has a closed circuit schematic, thermal qualification, EMC measurement, fault-injection result or provider acceptance in this study. A shorted segment can halt a shot or create an unsafe transient; segmentation cannot yet be credited as fail-operational. The permanent-magnet field and inverter transients may reach other payloads, so scheduling after primary separation is not a substitute for payload-specific magnetic and EMC analysis.

\section{Reliability and Failure Modes}\label{sec:fmea}
Table~\ref{tab:fmea} summarizes the principal failure modes in an FMEA form, with the mitigation designed into the architecture. The intended safety goals are to retain the satellite through ascent, prevent unintended release after any credible fault and recover a safe state when possible. Single-fault tolerance and graceful degradation have not been established for the feeder, bank, inverter or brake.

\begin{table}[t]
\caption{Principal failure modes and mitigations}
\label{tab:fmea}
\centering\footnotesize
\begin{tabular}{p{1.5cm}p{1.4cm}p{4.2cm}}
\toprule
Failure & Effect & Mitigation\\
\midrule
Sled jam & \textbf{Manifest stranded} & Caged escapement; controlled-disposal host. \textbf{The dual-cassette split bounds an \emph{escapement or gate} fault to half the manifest, but not a sled fault: one sled serves all twelve cells}\\
Latch fails & Early release & Latch loaded only on abort; inertia retains during accel; three-inhibit fire chain\\
Sensor fault & Wrong velocity & Redundant seat switches, encoder, photogate cross-check; no-fire on disagreement\\
Capacitor cell & Reduced energy & 32 series cells; one shorted cell drops rail 3\%, within margin\\
Inverter device & Phase loss & Segmented winding; dual gate drive; degraded-thrust continue\\
Magnet debond & Field loss & 84$\times$ bond margin at 200 $g$; taper-limited arrest\\
CubeSat misalign & Feed jam / tip-off & Seat switches + optical check; no-fire interlock\\
Brake fault & Sled overrun & Ring-spring hard stop backs eddy brake; motor regen trim\\
Controller fault & Loss of shot & Safe-state inhibits; watchdog; abort to 45\% stroke\\
\bottomrule
\end{tabular}
\end{table}

\section{Space Environment, EMC, and Standards}\label{sec:env}
LEO accommodation would require a selected material and component list checked for outgassing, atomic oxygen, thermal cycling, radiation, vibration and shock against the actual provider and mission standards \cite{ecss}. The current model proposes low-outgassing polymers, protected surfaces and N45SH magnets, but no supplier qualification record, launch-load test or environmental test is supplied. The calculated 109~Hz first mode and selected load margins apply to stated structural idealizations; they do not demonstrate assembly survivability.

The permanent-magnet sled is a payload compatibility concern. The modelled back-face field is 22.7~mT at 10~mm, 4.3~mT at 20~mm and 0.4~mT at 50~mm for the stated geometry. Across a 3U payload envelope, the calculated field is 61.1~mT at the near face and 0.341~mT at the far face. The near value exceeds a representative $\pm$100~$\mu$T magnetometer full scale by 611 times; even the far value exceeds it by 3.4 times. These are model results, not a qualified payload field map. No published VOLLEY ICD defines a keep-out radius, and the proposed steel septa and shielding have not been evaluated as installed hardware. Magnetometer recovery, magnetorquer operation, permanent magnetisation of payload parts and switching-transient coupling must be assessed with a named satellite. Timing a firing after primary separation does not remove the static-field exposure of stored spacecraft.

\section{Manufacturing, Cost, and Scalability}\label{sec:mfg}
A possible fabrication sequence uses a wound copper stator on an insulating former, a restrained fixture for assembly of the magnet arrays, and late loading of spacecraft after mechanism inspection. Proposed slot and gap tolerances of $\pm0.1$ and $\pm0.05$~mm are design targets, not supplier capabilities or a completed stack-up. The current STEP shapes omit fasteners, harness, joints and feed motion, and the side-fed reference assembly clashes; therefore no released manufacturing drawing set, assembly process or recurring maintenance interval can be claimed. An eventual ground article would require measured current-to-velocity calibration and acceptance of the complete release cycle.

The cost model is parametric and has no supplier quotations. In its assumed bill of materials, avionics, pulse storage and sensing dominate the estimated recurring hardware cost more than the magnet set; this ordering is conditional on unquoted prices and the incomplete installed system. The historical modeled shot draws 2.78~kJ, less than 1~Wh of electrical energy, but that is not a service-cost comparison: host power, storage, integration, qualification, mass, reliability, operations and any host propellant must be counted. A matched mission comparison with qualified spring systems, host manoeuvres, onboard propulsion and transport services remains open.

Ideal scaling trends ($v\propto\sqrt{L}$ at fixed acceleration) motivate a wider trade, but the payload-family table is model output, not accommodation of other CubeSat sizes. More payloads change feeder geometry, structure, reliability and host burden; the current twelve-slot reference already fails a width check. Lunar or deep-space use would require new interfaces, thermal/radiation design, mission dynamics and payload qualification, and is outside this study.

\section{Operational Concept and Maturation}\label{sec:conops}
The proposed operations sequence is launch with the deployer dormant; host and payload health checks; bank charge inside a provider-authorized window; one commanded release followed by independent confirmation of separation and safe sled arrest; and repetition only after fault review. Inhibit logic, an early-stroke abort window, bank passivation and eventual host disposal are design requirements, not demonstrated functions. POEM-3 provides a hosted-stage precedent \cite{poem3}, but no POEM or other provider has approved this sequence for VOLLEY.

The next evidence sequence is a reviewed feeder redesign, component-level bench tests, an instrumented integrated ground article, environmental tests against a named payload and host, and only then a provider-approved captive or deployment demonstration. Each stage needs predeclared acceptance bands and a decision review. No technology-readiness level is assigned from the present numerical results, and a future test does not automatically confer one.

\begin{figure}[t]
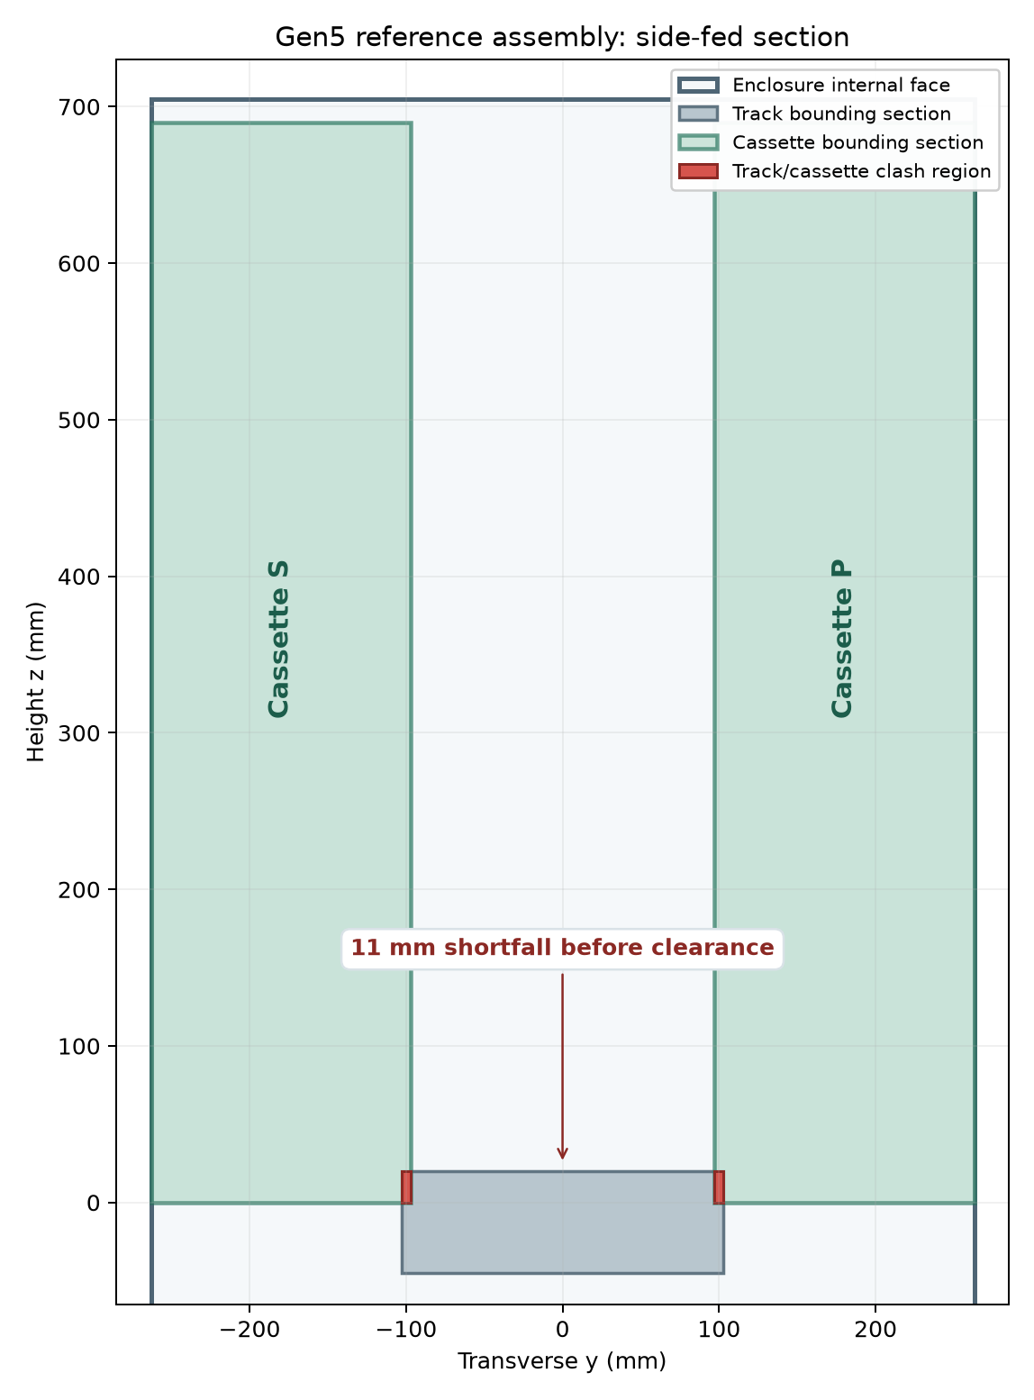
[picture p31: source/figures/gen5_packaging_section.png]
\centering
\caption{Gen5 side-fed reference-section failure. The two cassette widths and track require 537~mm within a 526~mm internal width before clearance. FreeCAD and CadQuery exact-solid intersections each find 32{,}915~mm$^3$ overlap per side. A new feed or enclosure configuration would require renewed analysis.}
\label{fig:packaging}
\end{figure}
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

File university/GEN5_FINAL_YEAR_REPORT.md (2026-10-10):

---
title: "VOLLEY Gen5 | Final-Year Project Report"
subtitle: "Computational design, evidence review, and engineering disposition"
author:
  - Adityavardhan Mishra
  - Pratham Chawla
date: "10 October 2026"
geometry: margin=20mm
papersize: a4
fontsize: 10pt
colorlinks: true
linkcolor: teal
toc: true
toc-depth: 1
classoption: titlepage
mainfont: DejaVu Sans
---

**Guide:** Vikas Gulia<br>
**Student PRNs:** Adityavardhan Mishra — 23070125054; Pratham Chawla — 23070125029<br>
**Department:** Mechanical Engineering, Symbiosis Institute of Technology<br>
**Document type:** Final-year project report prepared for academic review

> **Scope of this report.** VOLLEY is a system-level engineering design and computational research project. The Gen5 evaluated configuration and adverse numerical findings are documented; decisive force and mission closure remain open. The results are predictions, with numerical cross-checks where identified. Physical prototype testing, CubeSat qualification and provider accommodation belong to a later development phase. Gen6 is presented separately as future work.

Gen5 reference FreeCAD/STEP assembly visualized in Blender with enclosure hidden. Known side-fed clash remains; no physical article exists.
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

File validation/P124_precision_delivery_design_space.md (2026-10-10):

# P124 — precision-delivery design-space screen

**Result type:** exact ideal two-body orbital-energy conversion and minimum constant-acceleration stroke screen. This is a *requirements aid*, not a Gen5 rated-performance result or evidence of command precision.
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

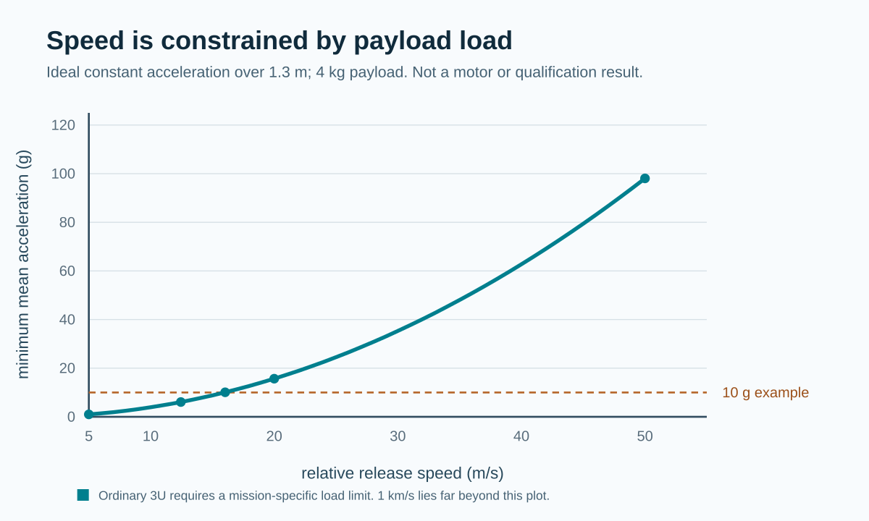
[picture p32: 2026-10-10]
figures/precision_delivery_design_space.png

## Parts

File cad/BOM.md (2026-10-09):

<!-- GENERATED by cad/tools/make_cad_package.py. Do not edit by hand:
     edit cad/parameters.json or analysis/mass_properties.py and re-run. -->

# Bill of materials

Masses are imported from [`analysis/mass_properties.py`](../analysis/mass_properties.py),
which builds the rollup from primitive solids and material densities. Nothing here is
re-entered by hand. Quantities and interface dimensions come from
[`parameters.json`](parameters.json).

> No line item has a vendor quotation. `analysis/cost.py` carries assumed prices and
> says so in its own header; no cost claim in this repository is supported, and none
> should be made from this table. It is a mass and materials list, not a purchase order.

> The earlier P10 enclosure omission was resolved by A46: enclosure skins, frames, radiator,
> equipment bays and brackets now have separate modelled line items below. These and other
> component masses remain estimates, not a weighed assembly or complete host-installed mass.

| # | Item | Qty | Material | Mass, kg | CG x, m | Notes |
|---:|---|---:|---|---:|---:|---|
| 1 | Track longerons (2x Al box section) | 2 | Aluminium 7075-T6 | 6.83 | 0.75 | box section, 4 mm wall |
| 2 | Stator copper (1.3 m, 60% fill) | 1 | Copper, oxygen-free | 6.29 | 0.65 | 162 conductors, 3-phase |
| 3 | Stator formers / potting (PEEK eq.) | 1 | PEEK, unfilled | 0.97 | 0.65 | formers and potting |
| 4 | Sled Halbach magnets (2 faces) | 1 | NdFeB N45SH, sintered | 3.67 | 0.15 | two faces, 8 mm thick |
| 5 | Sled Ti chassis (shell equivalent) | 1 | Ti-6Al-4V grade 5 | 0.74 | 0.15 | plate, see note below |
| 6 | Sled rollers / latch / backstop | 1 | Steel 440C + Al | 0.45 | 0.15 | 4 rollers, D30 x 16 |
| 7 | Eddy brake magnets + yoke | 1 | NdFeB + steel yoke | 1.68 | 1.42 | 2 tapered pole plates |
| 8 | Fixed brake hardware + ring spring (moving Cu fin is in sled) | 1 | Steel | 0.86 | 1.40 | ring-spring stop |
| 9 | Cassette shells (2x Al sheet eq.) | 2 | Aluminium sheet | 8.85 | 0.35 | see shell_construction_decision |
| 10 | Followers, gates, escapements (2x) | 2 | Al + A-286 pins | 2.60 | 0.30 | 2 gate pins D9 per cassette |
| 11 | Supercapacitor cells + busbars | 1 |  | 6.50 | 0.10 | 96 V, 6 F bank |
| 12 | PPU (SiC bridge, filters) | 1 |  | 4.00 | 0.10 | SiC inverter |
| 13 | Battery + avionics + IMU | 1 |  | 5.50 | 0.12 | sequencer, IMU |
| 14 | Harness | 1 |  | 2.50 | 0.60 |  |
| 15 | Thermal (pipes, radiator, MLI) | 1 | Al radiator | 6.00 | 0.70 | 0.32 m^2 radiator |
| 16 | ESPA bracket + fasteners | 1 | Aluminium | 9.00 | 0.35 | ring flange, 24 x M8 holes |
| 17 | Panels / closeouts | 1 | Aluminium, 2 mm skin | 5.50 | 0.75 | enclosure |
| 18 | Enclosure skins (2 mm Al, 6.077 m2 net, A46) | 1 |  | 32.82 | 0.50 |  |
| 19 | Enclosure frames and ribs (A46, 25 % of skin, declared) | 1 |  | 8.20 | 0.50 |  |
| 20 | Radiator (1600 x 200 x 3 mm Al, A46) | 1 |  | 2.59 | 0.45 |  |
| 21 | Equipment-bay boxes (4 bays, 1.5 mm Al, A46) | 1 |  | 1.87 | 0.30 |  |
| 22 | Fasteners and brackets (A46, 10 % of structure, declared) | 1 |  | 4.55 | 0.50 |  |
| 23 | Sled CAD reconciliation (P15, CAD-derived 9.445 kg) | 1 |  | 4.59 | 0.15 | see note |
| | MODELLED DRY TOTAL | | | 126.6 | 0.46 | A46 enclosure included; host installation unclosed |
| | LOADED (12 x 3U at 4 kg) | | | 174.6 | | |

Sled assembly: 9.45 kg, the CAD-derived value from the Gen3 STEP solids (P15).
This is the single mass the exit velocity is most sensitive to, and it is the mass of
unpocketed, as-drawn plates. Lightening the sled in CAD changes the operating point:
re-run `mass_properties.py` and then `motor_model.py` before quoting any number after
such a change. See P5, P8, P15.

## Off-the-shelf and standards-bound items

| Item | Spec | Source |
|---|---|---|
| Gate pins | 2 per cassette, D9 mm, A-286 | A22 resize, P37 |
| Cassette septa | 1.0 mm silicon steel | parameters.json |
| ESPA flange bolts | 24 x D9 mm on a D400 mm circle | ESPA ring interface |
| Payload envelope | 340.5 x 100 x 100 mm, 8.5 mm rails | CubeSat Design Specification rail interface |

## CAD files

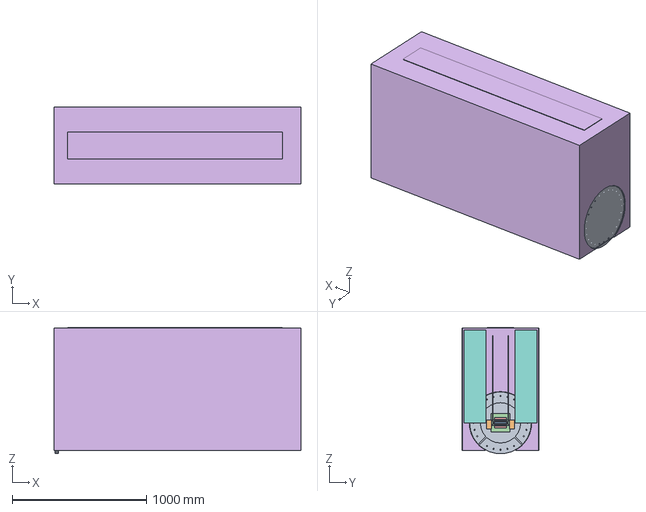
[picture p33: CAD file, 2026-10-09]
cad/step/feeder_candidate_r1/VOLLEY_Feeder_Assembly_FreeCAD_R1.step
1839.0 x 570.0 x 938.3 mm

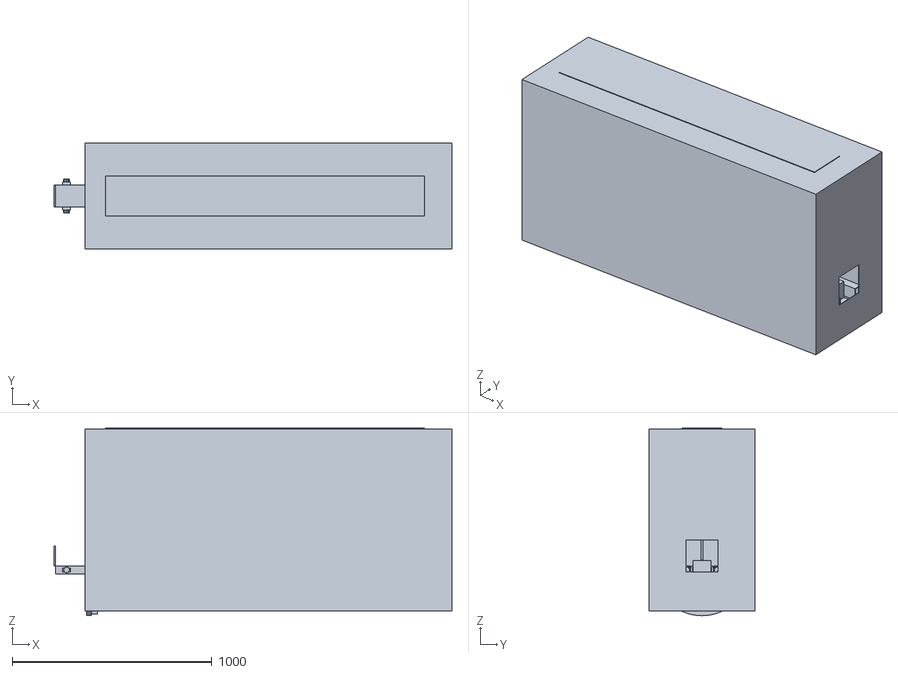
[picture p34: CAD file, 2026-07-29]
cad/stl/EMOCD_Assembly_Gen3.stl
1995.0 x 530.0 x 940.0

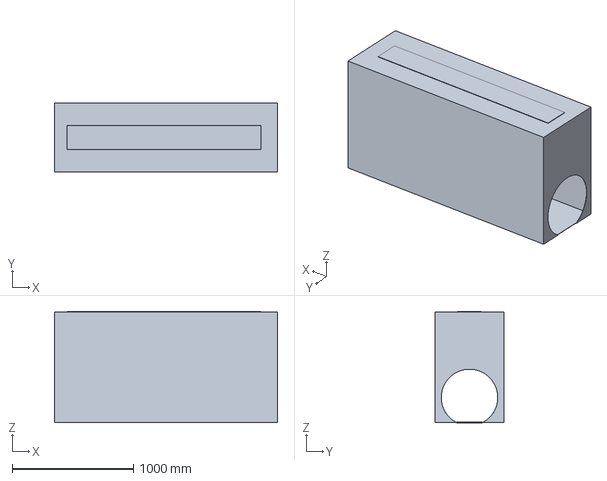
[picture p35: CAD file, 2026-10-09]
cad/step/feeder_candidate_r1/VOLLEY_Wide_Enclosure_R1.step
1839.0 x 570.0 x 917.0 mm

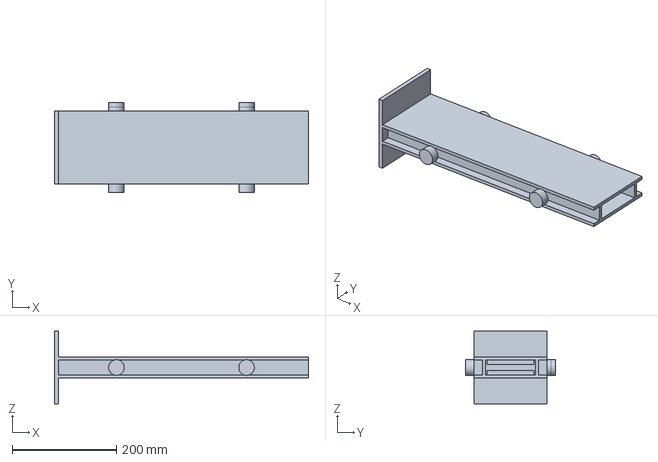
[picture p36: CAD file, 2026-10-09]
cad/step/freecad_gen5/VOLLEY_Sled_FreeCAD_Gen5.step
488.0 x 172.0 x 140.0 mm

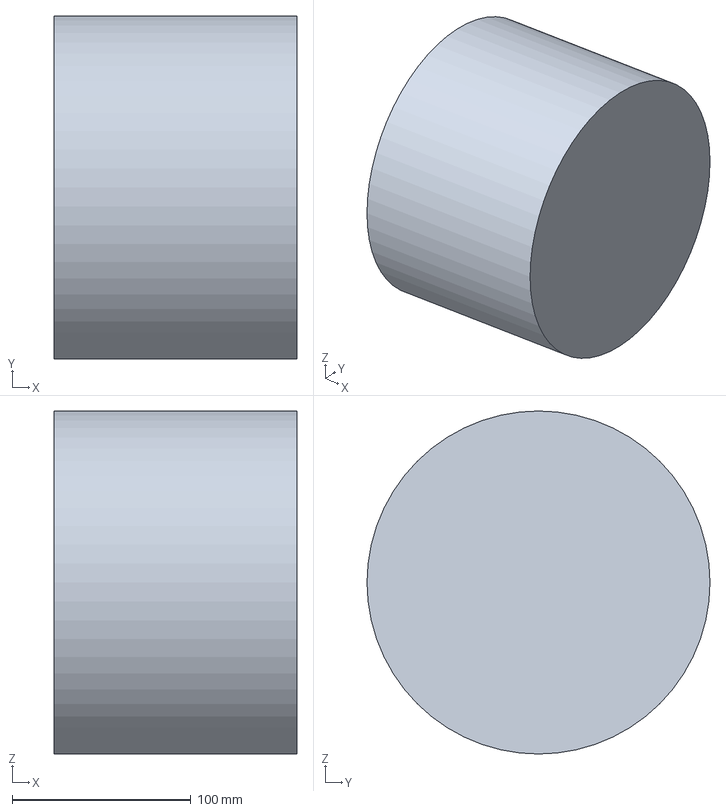
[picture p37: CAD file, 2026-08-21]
cad/step/gen6/VOLLEY_Reservoir_Gen6.step
136.0 x 192.0 x 192.0 mm

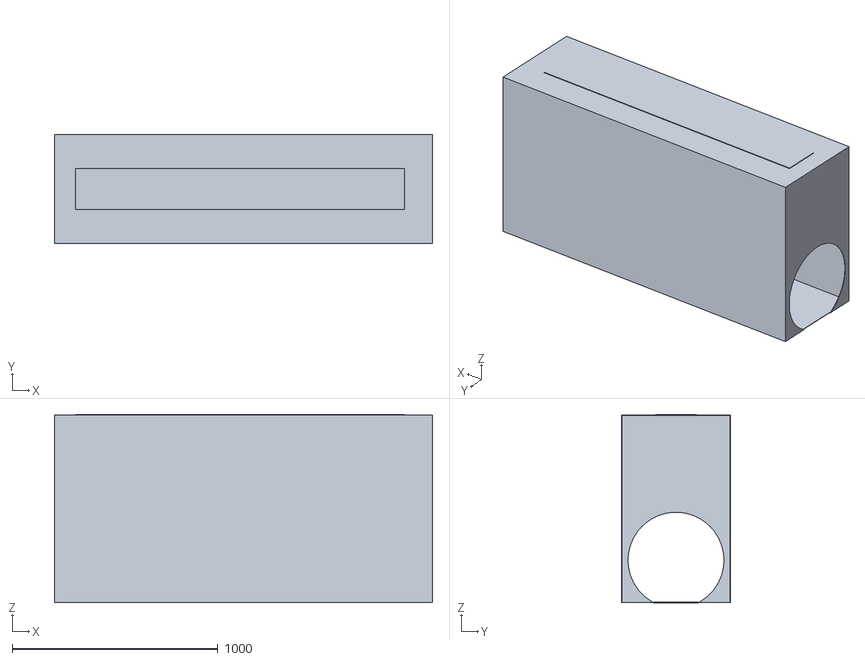
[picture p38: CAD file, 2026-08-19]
cad/stl/gen5_scad/enclosure.stl
1839.0 x 530.0 x 917.0

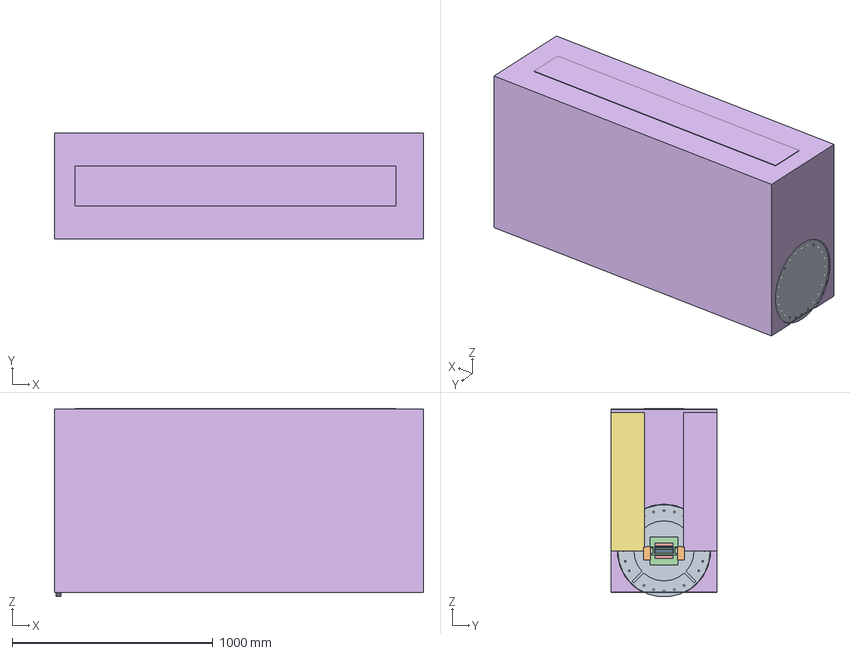
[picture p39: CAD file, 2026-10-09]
cad/native/Gen5_Review.FCStd
1839.0 x 530.0 x 938.3 mm
Interface ESPA
Track
Stator
Sled
Brake
Enclosure
Magazine S
Payload S01
Payload S02
Payload S03
Payload S04
Payload S05
Payload S06
Magazine P
Payload P01
Payload P02
Payload P03
Payload P04
Payload P05
Payload P06

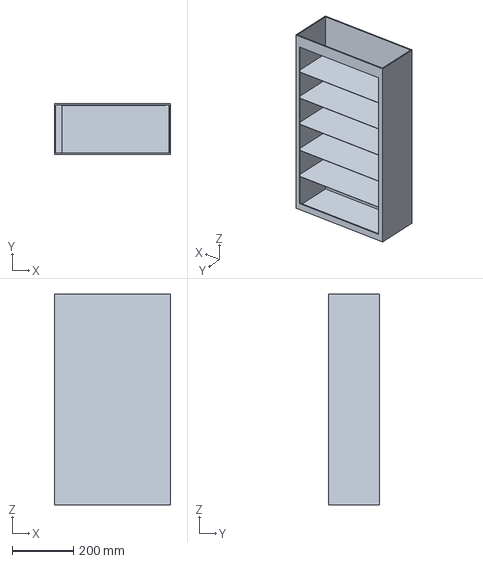
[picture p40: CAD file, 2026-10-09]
cad/step/feeder_candidate_r1/VOLLEY_Open_Cassette_S_R1.step
380.5 x 166.0 x 690.0 mm

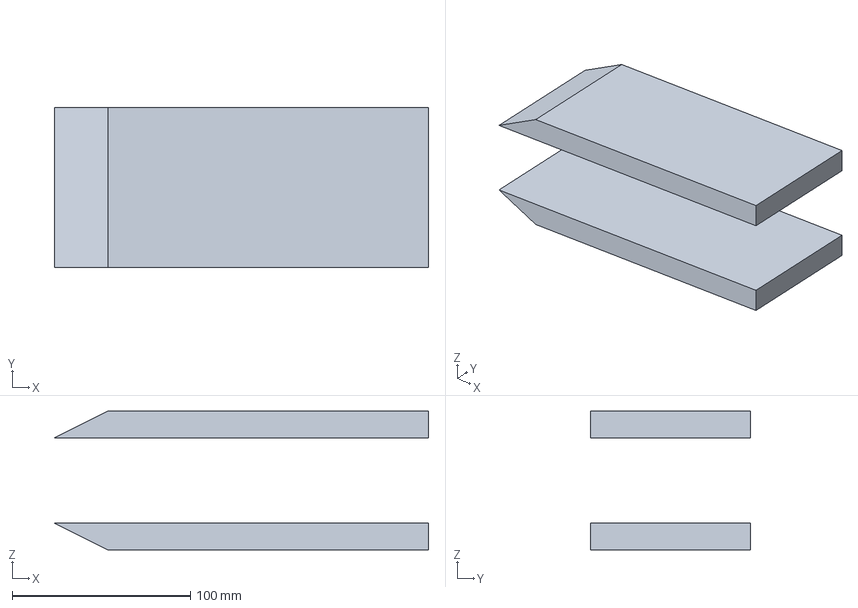
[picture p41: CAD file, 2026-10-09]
cad/step/freecad_gen5/VOLLEY_Brake_FreeCAD_Gen5.step
210.0 x 90.0 x 78.0 mm

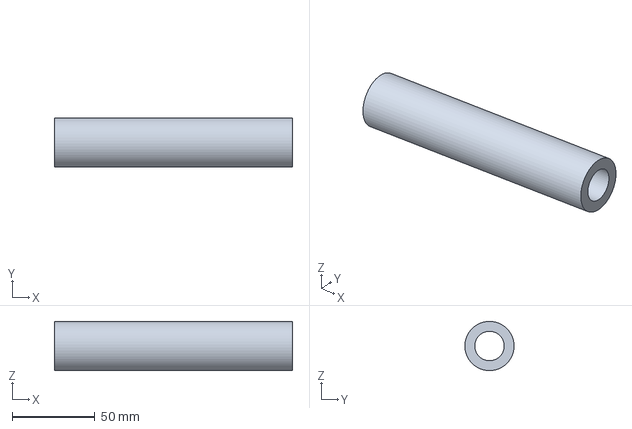
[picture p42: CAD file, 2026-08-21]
cad/step/gen6/VOLLEY_Trim_Stator_Gen6.step
144.0 x 29.8 x 29.8 mm

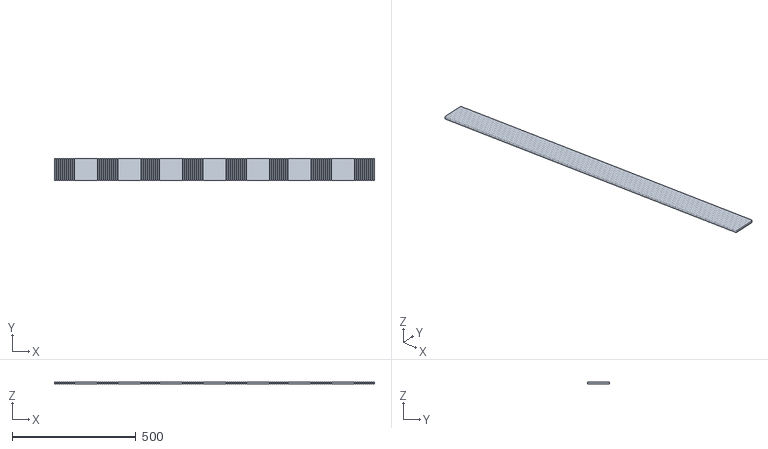
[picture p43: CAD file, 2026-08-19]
cad/stl/gen5_scad/stator.stl
1295.0 x 90.0 x 10.0

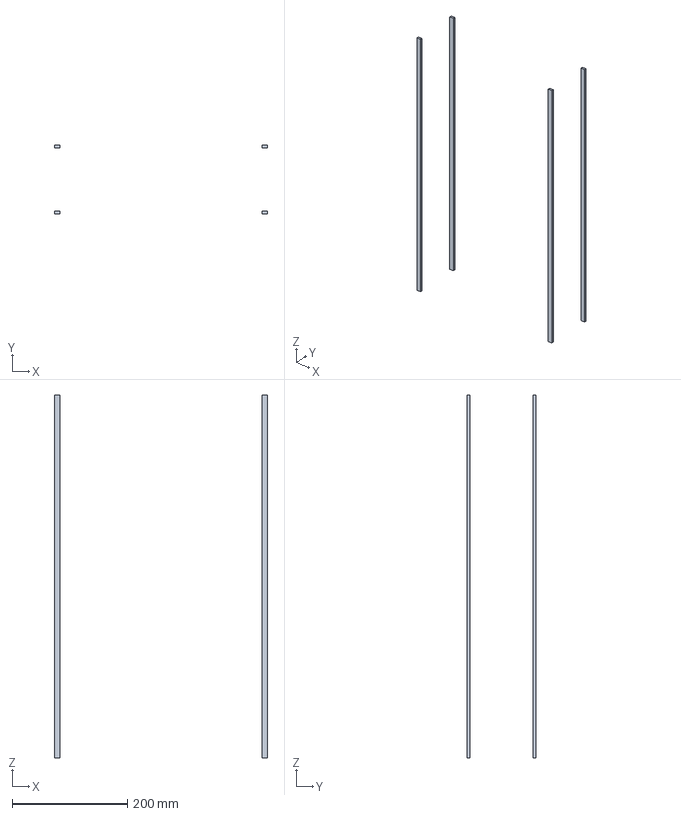
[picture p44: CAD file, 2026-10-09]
cad/step/feeder_candidate_r1/VOLLEY_Lift_Guides_R1.step
370.0 x 120.0 x 630.0 mm

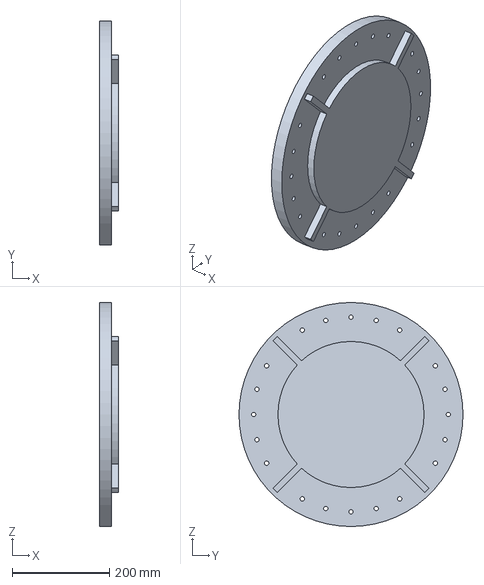
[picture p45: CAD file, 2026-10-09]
cad/step/freecad_gen5/VOLLEY_Interface_ESPA_FreeCAD_Gen5.step
40.0 x 460.0 x 460.0 mm

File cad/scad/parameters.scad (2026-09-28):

// GENERATED by cad/tools/make_scad_params.py from cad/parameters.json.
// Do not edit by hand: edit parameters.json and re-run.
//
// Every numeric leaf of the parameter file appears here as <group>_<key>. The
// non-numeric ones are skipped and named below, so nothing is dropped silently.
//
// skipped (not numeric): envelope_status
// skipped (not numeric): envelope_reconciliation_note
// skipped (not numeric): envelope_espa_grande_conflict
// skipped (not numeric): track_status
// skipped (not numeric): stator_topology
// skipped (not numeric): stator_belt_sequence
// skipped (not numeric): stator_phase_colours_A
// skipped (not numeric): stator_phase_colours_B
// skipped (not numeric): stator_phase_colours_C
// skipped (not numeric): stator_end_turns_modelled
// skipped (not numeric): stator_end_turns_note
// skipped (not numeric): stator_layer_count_decision
// skipped (not numeric): stator_status
// skipped (not numeric): sled_status
// skipped (not numeric): sled_provisional_note
// skipped (not numeric): magazine_gate_pin_material
// skipped (not numeric): magazine_septum_material
// skipped (not numeric): magazine_shell_construction_decision
// skipped (not numeric): magazine_status
// skipped (not numeric): magazine_gate_pin_diameter_note
// skipped (not numeric): payload_cell_insert_divider_axis
// skipped (not numeric): payload_cell_section_limit_origin
// skipped (not numeric): payload_cell_classes_accommodated
// skipped (not numeric): payload_cell_classes_refused_ThinSat
// skipped (not numeric): payload_cell_classes_refused_12U CubeSat
// skipped (not numeric): payload_cell_classes_refused_ChipSat / femtosat
// skipped (not numeric): payload_cell_status
// skipped (not numeric): payload_cell_provisional_note
// skipped (not numeric): brake_ring_spring_stop
// skipped (not numeric): brake_taper_purpose
// skipped (not numeric): brake_status
// skipped (not numeric): brake_provisional_note
// skipped (not numeric): interface_espa_flange_protrudes_through_aft_skin
// skipped (not numeric): interface_espa_status
// skipped (not numeric): payload_3u_corner_rail_standard
// skipped (not numeric): payload_3u_modelled_as
// skipped (not numeric): payload_3u_status
// skipped (not numeric): enclosure_skin_material
// skipped (not numeric): enclosure_muzzle_aperture_verified
// skipped (not numeric): enclosure_aft_cutout_profile
// skipped (not numeric): enclosure_bays_verified_clear_of_track
// skipped (not numeric): enclosure_status
// skipped (not numeric): enclosure_mass_note
// skipped (not numeric): legacy_study_store_gas

brake_arrest_g_cap = 200;
brake_pole_count = 2;
brake_pole_plate_thickness = 15;
brake_pole_taper_entry_length = 30;
brake_pole_width_y = 90;
brake_x_end = 1740;
brake_x_start = 1530;
enclosure_aft_flange_cutout_diameter = 466;
enclosure_bays_avionics_sequencer_x = [610, 760];
enclosure_bays_avionics_sequencer_y = [-255, -135];
enclosure_bays_avionics_sequencer_z = [-130, -50];
enclosure_bays_imu_unit_x = [790, 850];
enclosure_bays_imu_unit_y = [-255, -195];
enclosure_bays_imu_unit_z = [-130, -80];
enclosure_bays_ppu_sic_inverter_x = [330, 580];
enclosure_bays_ppu_sic_inverter_y = [-255, -115];
enclosure_bays_ppu_sic_inverter_z = [-130, -30];
enclosure_bays_supercap_bank_96V_6F_x = [0, 300];
enclosure_bays_supercap_bank_96V_6F_y = [-255, -115];
enclosure_bays_supercap_bank_96V_6F_z = [-180, -30];
enclosure_belly_notch_x_max = 2;
enclosure_belly_notch_x_min = -27;
enclosure_belly_notch_y_half_width = 110;
enclosure_muzzle_aperture_centre_y = 0;
enclosure_muzzle_aperture_centre_z = 70;
enclosure_muzzle_aperture_height_z = 160;
enclosure_muzzle_aperture_width_y = 160;
enclosure_muzzle_panel_x = 1805;
enclosure_radiator_area_m2 = 0.32;
enclosure_radiator_length = 1600;
enclosure_radiator_thickness = 3;
enclosure_radiator_width = 200;
enclosure_radiator_x_start = 70;
enclosure_radiator_z = 707;
enclosure_skin_thickness = 2.0;
enclosure_x_max = 1807;
enclosure_x_min = -32;
enclosure_y_half_width = 265;
enclosure_z_bottom_skin_outer = -207;
enclosure_z_top_skin_outer = 707;
envelope_extremes_max_mm = [1807, 265, 710];
envelope_extremes_min_mm = [-32, -265, -230];
envelope_installed_closed_mm = [1839, 530, 940];
legacy_study_drive_acceleration_g = 25.0;
legacy_study_drive_bore_mm = 15.805;
legacy_study_drive_commanded_force_N = 981.0;
legacy_study_drive_cradle_contact_lever_mm = 170.25;
legacy_study_drive_cradle_preload_N_per_contact = 201.7;
legacy_study_drive_exit_velocity_m_s = 30.54;
legacy_study_drive_exit_velocity_m_s_at_friction_allowance = 29.01;
legacy_study_drive_exit_velocity_m_s_zero_friction = 30.54;
legacy_study_drive_piston_area_mm2 = 196.2;
legacy_study_drive_stroke_mm = 2180.0;
legacy_study_drive_tube_wall_mm = 1.0;
legacy_study_store_chamber_volume_l = 2.0;
legacy_study_store_charge_pressure_bar = 50.0;
legacy_study_store_fill_orifice_mm = 1.0;
legacy_study_store_first_fill_s = 4.14;
legacy_study_store_reservoir_volume_conduction_l = 8.95;
legacy_study_store_reservoir_volume_isothermal_l = 8.25;
legacy_study_store_reservoir_volume_l = 9.55;
legacy_study_store_storage_pressure_bar = 200.0;
interface_espa_bolt_circle_diameter = 400;
interface_espa_bolt_hole_count = 24;
interface_espa_bolt_hole_diameter = 9;
interface_espa_flange_outer_diameter = 460;
interface_espa_flange_thickness = 25;
interface_espa_gusset_count = 4;
interface_espa_gusset_inner_radius = 50;
interface_espa_gusset_outer_radius = 220;
interface_espa_gusset_thickness = 12;
interface_espa_hub_plate_diameter = 300;
interface_espa_hub_plate_thickness = 15;
interface_espa_x_max = 0;
interface_espa_x_min = -25;
magazine_cassette_height_z = 690;
magazine_cassette_length_x = 380.5;
magazine_cassette_width_y = 166;
magazine_drive_bay_width = 30;
magazine_escapement_finger_count = 2;
magazine_follower_plate_thickness = 6.0;
magazine_follower_rib_count = 3;
magazine_gate_ascent_preload_N = 5900;
magazine_gate_frame_z_max = 626;
magazine_gate_frame_z_min = 46;
magazine_gate_pin_count = 2;
magazine_gate_pin_diameter = 9;
magazine_gate_pin_x_positions = [110, 290];
magazine_leadscrew_x_position = 200;
magazine_satellite_pitch_z = 104;
magazine_satellites_per_cassette = 6;
magazine_septum_thickness = 1.0;
magazine_septum_x_max = 375;
magazine_septum_x_min = 25;
magazine_septum_z_max = 646;
magazine_septum_z_min = 26;
magazine_shell_panel_thickness = 4.0;
payload_3u_corner_rail_count = 4;
payload_3u_corner_rail_size = 8.5;
payload_3u_height_z = 100;
payload_3u_instances_in_assembly = 12;
payload_3u_length_x = 340.5;
payload_3u_width_y = 100;
payload_cell_cell_length_x = 340.5;
payload_cell_cell_pitch_z = 104.0;
payload_cell_cell_section_y = 100.0;
payload_cell_cell_section_z = 100.0;
payload_cell_cells_per_cassette = 6;
payload_cell_cells_total = 12;
payload_cell_insert_divider_thickness = 1.5;
sled_airgap_per_side = 1.0;
sled_backstop_thickness = 8.0;
sled_chassis_plate_thickness = 6.0;
sled_chassis_web_thickness = 6.0;
sled_chassis_web_y_inner = 48;
sled_chassis_web_y_outer = 54;
sled_gap_shim_tolerance = 0.05;
sled_halbach_array_length = 340;
sled_halbach_array_width_y = 90;
sled_halbach_array_x_end = 570;
sled_halbach_array_x_start = 230;
sled_halbach_array_z_inner = 6;
sled_halbach_array_z_outer = 14;
sled_halbach_magnet_thickness = 8;
sled_overall_height = 140;
sled_overall_length = 488;
sled_overall_width = 140;
sled_payload_com_offset_above_thrust_line = 70;
sled_roller_base_span = 300;
sled_roller_count = 4;
sled_roller_diameter = 30;
sled_roller_width = 16;
sled_roller_x_offset_from_centre = 125;
sled_roller_y_inner = 70;
sled_roller_y_outer = 86;
stator_active_span_end = 1296;
stator_active_span_start = 0;
stator_active_width_y = 90;
stator_belt_pitch = 8.0;
stator_belt_thickness_z = 10.0;
stator_belt_width = 7.0;
stator_belt_z_max = 5;
stator_belt_z_min = -5;
stator_conductor_count = 162;
stator_conductors_per_phase = 54;
stator_insulation_gap = 1.0;
stator_pole_pitch = 24;
stator_wavelength = 48;
stator_winding_fill_factor_for_mass = 0.6;
track_acceleration_zone_end = 1300;
track_guide_rail_y_inner = 68;
track_guide_rail_y_outer = 88;
track_guide_rail_z_contact = 15;
track_guide_rail_z_outer = 22;
track_guide_rails_per_side = 2;
track_launch_lock_count = 2;
track_launch_lock_x_end = 50;
track_launch_lock_x_start = 30;
track_launch_lock_y_inner = 68;
track_launch_lock_y_outer = 78;
track_launch_lock_z_half_height = 14;
track_longeron_count = 2;
track_longeron_length = 1800;
track_longeron_z_max = 20;
track_longeron_z_min = -45;
track_overall_width = 205;
track_release_point = 1500;
track_roller_channel_y_inner = 67;
track_roller_channel_y_outer = 90;
track_roller_channel_z_half_height = 22;

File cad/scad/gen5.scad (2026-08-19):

// VOLLEY Gen5 -- an independent geometry implementation.
//
// WHY THIS EXISTS
// ---------------
// cad/build_gen5.py builds this machine with CadQuery, a B-rep kernel, and exports STEP.
// This file builds the same eight documents with OpenSCAD, a CSG kernel, and exports STL.
// Neither reads the other. Both read cad/scad/parameters.scad, which is built from
// cad/parameters.json, so the only thing they share is the parameter file that is supposed
// to be the single source of truth.
//
// That is the point. Everywhere else this project cross-checks a result by computing it a
// second way -- analytic against magpylib, both against a meshed FEM, orbit-averaged against
// Cowell. The geometry has never had that treatment: cad/parameters.json has been checked
// against exactly one model built from it. A disagreement between these two is either a bug
// in one of them or an ambiguity in the parameter file, and all three are worth knowing.
//
// A CSG model is not a manufacturing model, and neither is the B-rep one: no fillets,
// fasteners, harness routing or tolerancing exist in either.
//
// Usage:  openscad -D 'PART="track"' -o out.stl cad/scad/gen5.scad

include <parameters.scad>

$fn = 96;
PART = "all";

// ---------------------------------------------------------------- interface / ESPA

module interface_espa() {
    difference() {
        union() {
            // Flange ring, swept along +x from x_min.
            translate([interface_espa_x_min, 0, 0])
                rotate([0, 90, 0])
                    cylinder(h = interface_espa_flange_thickness,
                             d = interface_espa_flange_outer_diameter);
            // Hub plate at x = 0.
            rotate([0, 90, 0])
                cylinder(h = interface_espa_hub_plate_thickness,
                         d = interface_espa_hub_plate_diameter);
            // Four radial gussets at 45 deg, missing the track longerons.
            for (a = [45, 135, 225, 315])
                rotate([a, 0, 0])
                    translate([0, interface_espa_gusset_inner_radius,
                               -interface_espa_gusset_thickness / 2])
                        cube([interface_espa_hub_plate_thickness,
                              interface_espa_gusset_outer_radius
                                - interface_espa_gusset_inner_radius,
                              interface_espa_gusset_thickness]);
        }
        // Bolt circle, drilled through the flange only.
        for (i = [0 : interface_espa_bolt_hole_count - 1])
            rotate([360 * i / interface_espa_bolt_hole_count, 0, 0])
                translate([interface_espa_x_min - 1,
                           0, interface_espa_bolt_circle_diameter / 2])
                    rotate([0, 90, 0])
                        cylinder(h = interface_espa_flange_thickness + 2,
                                 d = interface_espa_bolt_hole_diameter);
    }
}

// ---------------------------------------------------------------- track

module track() {
    yo = track_overall_width / 2;        // beam runs to the track's overall width;
                                        // roller_channel_y_outer (90) is where the CHANNEL
                                        // ends, not where the longeron does.
    for (s = [1, -1]) {
        // Longeron beam.
        translate([0, s > 0 ? track_roller_channel_y_inner : -yo, track_longeron_z_min])
            cube([track_longeron_length, yo - track_roller_channel_y_inner,
                  track_longeron_z_max - track_longeron_z_min]);
        // Two guide rails per side, full length, inside the channel.
        for (zc = [track_guide_rail_z_contact, -track_guide_rail_z_contact])
            translate([0, s > 0 ? track_guide_rail_y_inner : -track_guide_rail_y_outer, zc])
                cube([track_longeron_length,
                      track_guide_rail_y_outer - track_guide_rail_y_inner,
                      track_guide_rail_z_outer - track_guide_rail_z_contact]);
        // Launch lock.
        translate([track_launch_lock_x_start,
                   s > 0 ? track_launch_lock_y_inner : -track_launch_lock_y_outer,
                   -track_launch_lock_z_half_height])
            cube([track_launch_lock_x_end - track_launch_lock_x_start,
                  track_launch_lock_y_outer - track_launch_lock_y_inner,
                  2 * track_launch_lock_z_half_height]);
    }
}

// ---------------------------------------------------------------- stator

module stator() {
    for (i = [0 : stator_conductor_count - 1])
        translate([stator_active_span_start + i * stator_belt_pitch,
                   -stator_active_width_y / 2, stator_belt_z_min])
            cube([stator_belt_width, stator_active_width_y,
                  stator_belt_z_max - stator_belt_z_min]);
}

// ---------------------------------------------------------------- sled

module sled() {
    L = sled_overall_length;
    W = sled_overall_width;
    H = sled_overall_height;
    a_off = (L - sled_halbach_array_length) / 2;
    x_aft = sled_halbach_array_x_start - a_off;
    zo = sled_halbach_array_z_outer;
    zi = sled_halbach_array_z_inner;

    for (s = [1, -1]) {
        // Chassis plate outboard of the magnets.
        translate([x_aft, -W / 2,
                   s > 0 ? zo : -zo - sled_chassis_plate_thickness])
            cube([L, W, sled_chassis_plate_thickness]);
        // Halbach array.
        translate([x_aft + a_off, -sled_halbach_array_width_y / 2, s > 0 ? zi : -zo])
            cube([sled_halbach_array_length, sled_halbach_array_width_y, zo - zi]);
    }
    // Side webs, outboard of the stator depth.
    for (s = [1, -1])
        translate([x_aft, s > 0 ? sled_chassis_web_y_inner : -sled_chassis_web_y_outer,
                   -(zo + sled_chassis_plate_thickness)])
            cube([L, sled_chassis_web_y_outer - sled_chassis_web_y_inner,
                  2 * (zo + sled_chassis_plate_thickness)]);
    // Backstop: the face the payload is pushed by.
    translate([x_aft, -W / 2, -H / 2])
        cube([sled_backstop_thickness, W, H]);
    // Four rollers.
    ry = (sled_roller_y_inner + sled_roller_y_outer) / 2;
    xc = x_aft + L / 2;
    for (dx = [-sled_roller_x_offset_from_centre, sled_roller_x_offset_from_centre])
        for (s = [1, -1])
            translate([xc + dx, s * ry - sled_roller_width / 2, 0])
                rotate([-90, 0, 0])
                    cylinder(h = sled_roller_width, d = sled_roller_diameter);
}

// ---------------------------------------------------------------- magazine cassette

module magazine_cassette() {
    lx = magazine_cassette_length_x;
    wy = magazine_cassette_width_y;
    hz = magazine_cassette_height_z;
    t  = magazine_shell_panel_thickness;
    union() {
        // Shell: closed panels, open at +Z (shell(-t) on the >Z face).
        difference() {
            translate([0, -wy / 2, 0]) cube([lx, wy, hz]);
            translate([t, -wy / 2 + t, t]) cube([lx - 2 * t, wy - 2 * t, hz]);
        }
        // Septa, one per cell boundary.
        for (i = [1 : magazine_satellites_per_cassette - 1]) {
            z = magazine_septum_z_min + i * magazine_satellite_pitch_z;
            if (z <= magazine_septum_z_max)
                translate([magazine_septum_x_min, -(wy - 2 * t) / 2, z])
                    cube([magazine_septum_x_max - magazine_septum_x_min,
                          wy - 2 * t, magazine_septum_thickness]);
        }
        // Retention gate frame.
        translate([0, -wy / 2, magazine_gate_frame_z_min])
            cube([lx, t, magazine_gate_frame_z_max - magazine_gate_frame_z_min]);
        // Two A-286 gate pins.
        for (x = magazine_gate_pin_x_positions)
            translate([x, -wy / 2, magazine_gate_frame_z_min
                       + (magazine_gate_frame_z_max - magazine_gate_frame_z_min) / 2])
                rotate([-90, 0, 0])
                    cylinder(h = wy, d = magazine_gate_pin_diameter);
    }
}

// ---------------------------------------------------------------- brake

module brake() {
    z = sled_halbach_array_z_outer + 10;
    t = brake_pole_plate_thickness;
    for (s = [1, -1])
        translate([0, -brake_pole_width_y / 2, s * z])
            rotate([90, 0, 0])
                translate([0, 0, -brake_pole_width_y])
                    linear_extrude(height = brake_pole_width_y)
                        polygon([[brake_x_start, 0],
                                 [brake_x_start + brake_pole_taper_entry_length, s * t],
                                 [brake_x_end, s * t],
                                 [brake_x_end, 0]]);
}

// ---------------------------------------------------------------- payload proxy
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

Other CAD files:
cad/step/feeder_candidate_r1/VOLLEY_Feeder_Assembly_R1.step
analysis/femm/emocd_cross_section.dxf
cad/native/Feeder_Candidate_R1.FCStd
cad/stl/VOLLEY_Reservoir_HistoricalStudy.stl
cad/stl/VOLLEY_Trim_Stator_HistoricalStudy.stl
cad/step/feeder_candidate_r1/VOLLEY_Open_Cassette_P_R1.step
cad/step/freecad_gen5/VOLLEY_Enclosure_FreeCAD_Gen5.step
cad/step/freecad_gen5/VOLLEY_Magazine_Cassette_FreeCAD_Gen5.step
cad/step/freecad_gen5/VOLLEY_Payload_3U_FreeCAD_Gen5.step
cad/step/freecad_gen5/VOLLEY_Stator_FreeCAD_Gen5.step
cad/step/freecad_gen5/VOLLEY_Track_FreeCAD_Gen5.step
cad/step/gen1/EMOCD_Assembly_Gen1.step
cad/step/gen1/EMOCD_Brake_Gen1.step
cad/step/gen1/EMOCD_Deployer_Assembly_Gen1.step
cad/step/gen1/EMOCD_Enclosure_Gen1.step
cad/step/gen1/EMOCD_Interface_ESPA_Gen1.step
cad/step/gen1/EMOCD_Magazine_Cassette_Gen1.step
cad/step/gen1/EMOCD_Payload_3U_Gen1.step
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

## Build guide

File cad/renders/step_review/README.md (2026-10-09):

# Gen5 and R1 STEP-derived review images

These six JPEGs are **Blender visualizations of STEP B-reps**, tessellated with FreeCAD 1.0. The native FreeCAD documents supply each instance placement and a link to its source STEP part. The exporter reopens every named STEP, checks its volume and placed bounds against the native document, and writes temporary OBJ display meshes. Blender reads those meshes and adds only materials, lights, a floor, cameras and the evidence labels visible on each JPEG. [PROVENANCE.json](PROVENANCE.json) lists the source hashes, included and hidden instances, JPEG hashes and evidence limit for each view.

| Image | What it shows | Evidence boundary |
|:--|:--|:--|
| [Gen5 open reference](gen5_reference_open.jpg) | Twenty-instance reference placement, enclosure hidden | The side-fed track and cassettes still intersect; no physical article |
| [Gen5 closed envelope](gen5_reference_closed.jpg) | Outer reference package | Conceals the known internal clash; no provider envelope approval |
| [Gen5 top view](gen5_fit_plan.jpg) | Track and cassette reference placement, payloads and enclosure hidden | The 11 mm shortfall comes from the [exact-solid audit](../../../validation/P116_gen5_assembly_packaging.md), not image scaling |
| [Gen5 drive detail](gen5_drive_detail.jpg) | Cropped track, stator and sled | No selected winding, control or contact qualification |
| [R1 open candidate](r1_candidate_open.jpg) | Separate widened candidate, enclosure hidden | Scripted routes clear; lift actuator and retention remain undesigned |
| [R1 top view](r1_candidate_plan.jpg) | Candidate cassette and track placement | Unselected geometry, no revised installed mass or host approval |

Regenerate from this repository root with:

```bash
/usr/bin/python3 cad/tools/export_step_view_meshes.py
blender -b --factory-startup -P cad/tools/render_step_review.py -- --mesh-manifest /tmp/volley-step-review-meshes/meshes.json --samples 64
```

The OBJ files in `/tmp` are display meshes; the released geometry remains the source [Gen5 STEP set](../../step/gen5/), [R1 STEP set](../../step/feeder_candidate_r1/) and [FreeCAD review documents](../../native/). The images do not show manufactured surface finish, hardware buildability, moving clearance, tolerances, electrical hardware or payload qualification. The conventional three-dimensional render is evidence of **geometry depiction only**.

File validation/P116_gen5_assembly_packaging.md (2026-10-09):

# P116 — Gen5 reference assembly and packaging screen

**Run:** 9 October 2026. **Disposition:** a named 20-instance review STEP is released, and its stated side-fed reference arrangement **fails** geometric interference. It is not a flight assembly, motion study or an approved interface.

The [assembly generator](../cad/build_review_assembly.py) imports the eight Gen5 STEP parts, places the interface, track, stator, sled, brake and enclosure, adds two magazine cassettes and twelve 3U payload proxies, and exports a named [assembly STEP](../cad/step/gen5/VOLLEY_Review_Assembly_Gen5.step). The [machine-readable report](../cad/REVIEW_ASSEMBLY.json) pins input hashes, placements and exact-solid overlap. A repeat export gave the same SHA-256 after the STEP header was normalized. The [cross-section](../figures/gen5_packaging_section.svg) draws the declared layout, not a manufacturing drawing.

FreeCAD 1.0 also imports the eight solids into a [native FCStd document](../cad/native/Gen5_Review.FCStd), re-exports [eight part STEP files](../cad/step/freecad_gen5/) and a [20-instance assembly STEP](../cad/step/gen5/VOLLEY_Review_Assembly_FreeCAD_Gen5.step), and reads the export back as a valid B-rep. Its independent exact-solid intersection gives the same 32,915 mm³ on each side; software version, hashes and limits are in the [FreeCAD export JSON](../cad/FREECAD_EXPORT.json) and the [CAD review PDF](../cad/GEN5_CAD_REVIEW.pdf). The imported parts are editable in placement and grouping but have no native FreeCAD parametric feature history.

For this side-fed reference, each 166 mm-wide cassette is placed against the internal side face of the 530 mm-wide, 2 mm-skin enclosure. Internal clear width is **526 mm**. Two cassettes plus the 205 mm-wide track need **537 mm before any clearance**, an **11 mm shortfall**. At the declared 200 mm cassette x offset and z=0..690 mm, exact B-rep intersections find **32,915 mm³ track/cassette overlap on each side**. The cassettes also have zero side-wall clearance. The reference placement therefore does not pass fit. A different vertical feed, cutout or larger enclosure could alter the outcome, but none is modeled or cleared here.

This assembly does not resolve feeder motion, retention, stator end turns, wiring, fasteners, tolerance stacks, thermal growth, structural load paths or an actual CubeSat/host ICD. STEP proxy volumes must not be turned into the 126.6 kg model rollup: materials, fill, components and several masses use different assumptions. The current 3U design should be described as an evaluated computational configuration **with a packaging defect**, not a completed manufacturable product.

Reproduce with `python3 cad/build_review_assembly.py` after `cad/build_gen5.py`; the part hashes in the report allow a reviewer to establish which solids were assembled. Run `python3 cad/plot_review_packaging.py` to rebuild the section figure.

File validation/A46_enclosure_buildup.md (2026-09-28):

# A46, the enclosure, built up from line items instead of guessed

**Bands declared 2026-08-16, before `analysis/enclosure_buildup.py` existed.**
Verify with `git show --stat <this commit> -- analysis/enclosure_buildup.py`, which must return nothing.

---

## Why this run exists

[P68](../OPEN_PROBLEMS.md). [A45](A45_stage_credit.md) found that ADR-032's first falsifier
fires, and that the single largest item in the 43.33 kg stage credit is the 8.00 kg enclosure,
radiator and packaged-avionics line, which is [P10](../OPEN_PROBLEMS.md), a mass this repository
records as never itemised. At 18.5 % of the credit against a 16.5 % break-even, that one line
fires the falsifier on its own.

P10's own text says what to do: *"Add line items once masses are estimated."* It has said so
since the enclosure document was drawn, and instead an 8.00 kg placeholder with no derivation
was entered on 2026-08-13 so that a caveated number would be auditable where a hole was not. That
was the right move at the time and it was never meant to be the answer.

The geometry to do it properly has existed all along, in `cad/parameters.json` under
`enclosure`: skins, thickness, envelope, three apertures, radiator dimensions and four equipment
bays with coordinates.

## What is being built

The Gen5 enclosure, because that is what the placeholder is in and what A35's ledger carries.
historical study deletes it, the stage provides the skin, which is exactly why the number matters: it is
the largest thing being credited away.

| Element | From |
|---|---|
| Skins | `enclosure` envelope, less the muzzle aperture, the Ø466 aft flange cutout and the belly notch |
| Frames and ribs | a declared fraction of skin mass |
| Radiator | `radiator_length` × `radiator_width` × `radiator_thickness` |
| Equipment-bay boxes | the four `bays` volumes, walled at a declared thickness |
| Fasteners, brackets, tie-downs | a declared fraction of the structure |

Two skin cases, because `parameters.json` specifies one and flight hardware uses the other.
The file says 2 mm monolithic aluminium. Real spacecraft panels of this size are honeycomb
sandwich. Both are computed; the sandwich areal density is declared and swept.

## Declared inputs

| | Value | Because |
|---|---|---|
| Aluminium density | 2700 kg/m³ | as `mass_properties.py` already uses |
| Sandwich areal density | **3.0 kg/m²**, swept 2.0 – 4.0 | an aluminium honeycomb panel with thin facesheets; the sweep is wider than the spread between real designs |
| Frames and ribs | **25 %** of skin mass | a declared fraction, with no derivation, and named as such |
| Bay wall thickness | **1.5 mm** aluminium | thinner than the skin because a bay is not a load path |
| Fasteners and brackets | **10 %** of structure | a declared fraction, named as such |

Three of those five are guesses. They are smaller guesses than the one they replace, and each
is stated rather than folded into a total.

---

## Acceptance bands

Declared before the script. Not to be edited after the run.

| # | Band | FAIL if |
|---|---|---|
| **1** | Envelope read from `parameters.json` is **1839 × 530 × 914 mm** within 1 mm | The run is not reading the authoritative geometry |
| **2** | Aperture area subtracted is **> 0** and **< 5 %** of gross skin area | The cutouts are being ignored or double-counted |
| **3** | **Built-up mass, monolithic 2 mm case, ≤ 8.0 kg** | The placeholder is low, the dry-mass floor rises again, and every kg-per-satellite figure in the project moves the wrong way |
| **4** | **Built-up mass, sandwich case, ≤ 8.0 kg** | Same, and it cannot be blamed on the parameter file specifying a heavy skin |
| **5** | Sandwich case is **lighter** than monolithic across the whole areal-density sweep | The model is not behaving |
| **6** | Radiator area **0.32 m²** rejects the campaign-average heat load at 300 K, ε = 0.85, to a 4 K sink | The radiator is undersized and the enclosure has a second defect |
| **7** | Every line item traces to a **parameter or a declared input** — zero undeclared | The buildup has a hole of its own, which is the thing it exists to remove |
| **8** | **A45's P10-only case improves** — added mass per satellite on the corrected lump is **≤ 2.069 kg** | The correction makes P68 worse rather than better, and the honest range in `KILL_CRITERIA.md` widens again |

## Predictions, recorded before the run

1. **Bands 3 and 4 both fail, and band 3 badly.** Six square metres of 2 mm aluminium is about
   33 kg before anything is attached to it. I expect the monolithic case near 35 kg and the
   sandwich case near 22 kg, against a placeholder of 8.
2. **Band 8 therefore fails too**, and P68 gets worse rather than better: a bigger P10 lump is a
   bigger thing being credited to the stage.
3. **Band 6 passes comfortably.** The campaign-average dissipation is a couple of watts against a
   radiator that should reject over a hundred.
4. `KILL_CRITERIA.md` already flagged a plausible 20 kg of missing mass. I expect this run to
   land near or above that figure, which would mean the file's own warning was closer than the
   placeholder chosen instead of it.

## Result

**RUN 2026-08-16. Five of eight bands pass. The three failures are bands 3, 4 and 8, and the
placeholder is low by between 3.7 and 6.3 times.

| # | Band | Result | |
|---|---|---|---|
| 1 | envelope is 1839 × 530 × 914 mm within 1 mm | exact | **PASS** |
| 2 | aperture area > 0 and < 5 % of gross | 3.23 % | **PASS** |
| 3 | monolithic buildup ≤ 8.0 kg | **50.04 kg** | **FAIL** |
| 4 | sandwich buildup ≤ 8.0 kg | **29.98 kg** | **FAIL** |
| 5 | sandwich lighter than monolithic across the sweep | yes | **PASS** |
| 6 | radiator rejects the campaign-average load | 125 W against 1.89 W | **PASS** |
| 7 | every line item traces to a parameter or a declared input | 0 undeclared | **PASS** |
| 8 | A45's P10-only case improves | **2.069 → 3.901 kg/sat** | **FAIL** |

### The buildup

6.280 m² of gross box area, 3.23 % cut away by the muzzle aperture, the Ø466 aft flange cutout
and the belly notch, leaving 6.077 m² of skin.

| Monolithic 2 mm aluminium | kg | | Sandwich at 3.0 kg/m² | kg |
|---|---:|---|---|---:|
| Skins | **32.82** | | Skins | **18.23** |
| Frames and ribs | 8.20 | | Frames and ribs | 4.56 |
| Radiator | 2.59 | | Radiator | 2.59 |
| Equipment-bay boxes | 1.87 | | Equipment-bay boxes | 1.87 |
| Fasteners and brackets | 4.55 | | Fasteners and brackets | 2.73 |
| **TOTAL** | **50.04** | | **TOTAL** | **29.98** |

Against a placeholder of 8.00 kg. The sweep runs 21.62 kg at 2.0 kg/m² to 38.34 kg at 4.0, so
no plausible panel technology brings this near the placeholder. The skins alone are 2.3 times
it at the lightest sandwich in the sweep.

### Why the placeholder was so far out

It was never an estimate of anything. [P10](../OPEN_PROBLEMS.md) records it as *"an 8.0 kg
placeholder with no derivation"*, entered on 2026-08-13 explicitly so a caveated number would be
auditable where a hole was not, and chosen as *"the lean end"* of a range whose upper bound
`KILL_CRITERIA.md` had already put at a plausible 20 kg.

That file's warning was closer than the number chosen instead of it, and it was still low:
29.98 kg at a realistic panel, 50.04 kg as the parameter file actually specifies.

### What it costs, stated rather than absorbed

The parameter file specifies 2 mm monolithic aluminium skins, so 50.04 kg is what the design
as recorded weighs. A honeycomb sandwich would give 29.98 kg, and adopting one is a design
decision this project has not taken, it is not a correction and is not applied here.

| | Before | After, as specified |
|---|---:|---:|
| Enclosure line | 8.00 kg placeholder | **50.04 kg**, five line items |
| Dry mass | 84.5 kg | **126.5 kg** |
| Dry mass per 3U satellite | 7.042 kg | **10.54 kg** |
| Kill criterion 1 | crossed 3.5× | **crossed 5.3×** |
| A45's P10-only added mass | 2.069 kg/sat | **3.901 kg/sat** |

**Band 8 fails and P68 gets worse, exactly as predicted.** A bigger P10 lump is a bigger thing
being credited to the stage, so ADR-032's first falsifier fires harder rather than softer.

Nothing here is a new physical problem. The mass was always there; the repository was carrying
a number that said otherwise, and said so in writing. What changes is that the figure is now
derived, and every kilogram of it points at a line in `parameters.json`.

### The predictions

Three of four held cleanly. The first held in direction and missed in magnitude, both cases low
by about 40 %.

1. *"Monolithic near 35 kg, sandwich near 22 kg."* 50.04 and 29.98. Direction right, both
   numbers low. I under-counted what frames, bay boxes and fasteners add on top of skin.
2. *"Band 8 fails and P68 gets worse."* **2.069 → 3.901 kg per satellite.** Held.
3. *"Band 6 passes comfortably."* **125 W against 1.89 W.** Held.
4. *"Near or above the 20 kg `KILL_CRITERIA.md` flagged."* Above it in both cases. Held.

## What this run does not do

- No doublers, local reinforcement, expansion joints, surface treatment or connectors. All of
  those add, so this is a floor for the second time in the same line item.
- Three of the five inputs are declared guesses, the frame fraction, the bay wall thickness
  and the fastener fraction. They are smaller guesses than the one they replace and each is named.
- It does not choose a panel technology. Both cases are reported and the parameter file's
  monolithic specification is what the rollup carries.
- It does not re-open the rest of A35's ledger, and it changes no other line.

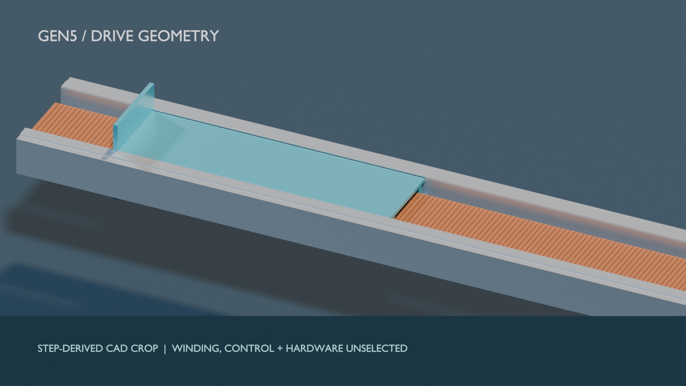
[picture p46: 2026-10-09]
cad/renders/step_review/gen5_drive_detail.jpg

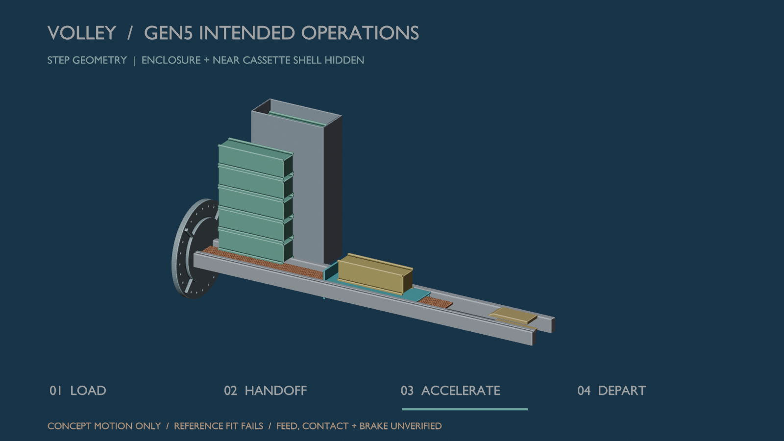
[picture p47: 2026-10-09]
cad/renders/sequence/step_03.png

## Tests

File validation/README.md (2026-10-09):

# Validation plan

> **Current finite-force finding (P118–P122).** The finite-array/stator 3-D analytic integral gives 1.042 kJ ideal work and 12.448 m/s under ideal phase, challenging the historical 16.029 m/s periodic shot. A separate [2-D finite-element screen](P119_gen5_finite_force_fem2d.md) gives 1.082 kJ, without depth end effects. The [conditional bank/trajectory rerun](P120_gen5_finite_coupled_shot.md) gives 12.448 m/s and 2.099 kJ gross for the full-winding assumption; no selected winding, inverter or hardware validates this rating. See the [matched mission screen](../docs/MATCHED_MISSION_REFERENCE.md). The older run-sheet count below describes the historical A-series table.

> **P121–P122 follow-up.** [P121](P121_gen5_finite_force_surface3d.md) independently integrates full-depth finite-cuboid force with a surface-charge formulation and returns 1.042 kJ ideal work under shared inputs. [P122](P122_gen5_finite_force_sensitivity.md) records deterministic gap/depth scenarios, including 0.907 kJ at a 14 mm face gap. Neither selects hardware or measures physical tolerances.

Independent cross-checks of the claims in `analysis/`. The historical A-series
table below contains 73 rows; newer P-series review checks are linked above. A73 is
declared and executing.

> ### This index was nineteen rows short until 2026-08-30, and said so nowhere
>
> It opened by describing *"nineteen of the twenty-one below"* while the directory held 73 files.
> Fifteen run sheets written between A15 and A34 and every run from A66 onward were absent, so a
> reader taking this page as the index of the validation work would have missed A72's finding
> entirely. Nothing checked the table against the directory; the counts gate checks how many run
> sheets exist and never checked whether they were listed.
>
> The missing rows are added below and the header now states a number that can be recomputed from
> `ls`. The rows for A15 and A28 to A34 were written from those run sheets' own Result headings on
> the day the gap was found, seventeen days after the last of them ran, and they are shorter than
> the rows written at the time.

## Why it exists

This directory was written when `PROVENANCE.md` could point at only two cross-checks, the
Halbach field (analytic vs magpylib) and orbital decay (orbit-averaged vs Cowell RK4), both
internal, and the field one analytic-against-analytic, so not confirmation by a different
physical method (`OPEN_PROBLEMS.md` E2).

That has changed, and not uniformly in the project's favour. A1 put a meshed PDE solve
against K<sub>t</sub> and agreed to 0.03 % after correcting shared quadrature. A4 put CalculiX against the chassis and it passed.
A12 put two independent numerical methods against the array attraction and found the published
value 37 % high. And A5 failed: an independent propagator falsified an invariance claim
that was in the paper's own abstract.

What has still never happened is a measurement. Every row below is one model against
another model (E4). Each analysis closes a specific named item.

| # | Analysis | Tool | Closes | Status |
|---|---|---|---|---|
| A1 | Airgap field, 2-D magnetostatic | scikit-fem + gmsh (FEMM substituted) | E1 (2-D half), E2 (partly) | RUN 2026-07-29, verdict PARTIAL: K<sub>t</sub> agrees to 0.03 % after correcting shared quadrature, two bands missed with causes (P20, P21) |
| A4 | Sled chassis structural | CalculiX ccx 2.21 | P5, P8 | RUN 2026-07-28: as-drawn plate passes all three bands |
| A5 | Orbital lifetime and seeding | GMAT R2022a | E6, hardens x1.80 | RUN, verdict FAIL on invariance. See [`../docs/RESULTS.md`](../docs/RESULTS.md) |
| A9 | Decay rate against flown CubeSats (TLE history) | Space-Track + numpy | E6, against reality rather than another model | NOT RUN, blocked by network policy here and re-tested 2026-07-31. Candidate objects now shortlisted in the sheet, so this is an afternoon elsewhere |
| A6 | Conjunction probability | scipy 2-D Pc (CARA substituted) | P1, not closed | CORRECTED 2026-08-03: fixed-shape claim retracted; current slab bound 4.4e-5, two of five bands, three VOID, P1 open |
| A7 | Separation and tip-off | Project Chrono | E7-adjacent | SUPERSEDED 2026-08-20 by [A23](A23_tipoff_release.md) and [A34](A34_cradle_restitution.md), which answered it, ideal release 0 °/s, skew tolerance 50.6 µs, and the cradle rattle settles in 27.25 ms of a 146.4 ms stroke leaving *exactly zero* residual rate. A7 itself stays correctly unrun. A7-R RUN 2026-08-05 instead: Chrono is unavailable and the release mechanism is undefined, so the tolerance was computed rather than the rate, the full push may act unbalanced for only 50.7 µs before the 2 °/s band breaks |
| A8 | Pulse-power chain | ngspice / PySpice | E17 | RERUN 2026-08-05 as A8-R2 at the corrected point: six of six bands, exit velocity agrees to 0.016 % |
| A10 | Shot against a realistic bank ESR | `motor_model.shot()` | nothing; opened P26 | RERUN 2026-08-03: hard ceiling 68 mohm, five of six bands, one VOID |
| A11 | Regenerative recovery of sled energy | `motor_model.regen_brake()` | nothing; asks what R5 did not | RERUN 2026-08-03: 291.4 J recovered, eight of eight bands. Superseded as a current figure: that run integrated over the 240 mm section [ADR-030](../docs/adr/030-apply-the-depth-resolved-thrust-constant.md) removed. At the 39 mm that survives, recovery is 47.0 J, 3.9 % of the sled's energy (P97) |
| A12 | Inter-array attraction, two numerical methods | magpylib + surface Maxwell stress | P17 | CORRECTED 2026-08-03: extended stress plane 2680.0 N vs 2686.6 N volume force; five of five bands |
| A13 | Indexing and sled-return attitude disturbance | momentum bookkeeping | E24 | CORRECTED 2026-08-03: transient-rate rows 3/4 FAIL, row 7 VOID; ideal residual rate is zero and the cadence conclusion is superseded |
| A14 | EMI scoping: payload coupling and comms | `drive_electrical` + magpylib | advances E12; opened P34 | RUN 2026-08-05, verdict PARTIAL: six of eight bands, band 4 FAIL at 611x, band 5 VOID. The dominant term is the static magnet field, not the drive |
| A16 | Gen4 finite-stator thrust vs sled station | magpylib | E27 | RUN 2026-08-05: full-overlap thrust reproduces `F_cmd` to 0.000 %; Gen4 reaches 13.390 m/s, 81.7 % of Phase I, an upper bound |
| A17 | Ripple chirp through the track modes | scipy SDOF | E23; opened P36 | RUN 2026-08-05, verdict FAIL: 8.18x amplification at the fundamental crossing of the 109 Hz mode, and Q is not the variable that saves it |
| A18 | Brake, magnet eddy, fin transient, launch restraint, standoff | numpy + Miles | E20, E19, E26, E22, and E10's analysis half; opened P37 | RUN 2026-08-06: E19/E26/E22 pass, E20 passes only for a 0.4-0.5 T pole field, E10 FAILS at every Q |
| A20 | Reachable orbit envelope vs host Δv budget | numpy + `astro.py` | nothing; quantifies ADR-024, advances PII-6 | RUN 2026-08-10, verdict band 1 FAIL: the band named a two-burn Hohmann and its limit was computed for one burn. Band 3 caught a sign bug in the script. Host supplies 56 % of the altitude extent at 100 m/s |
| A21 | VOLLEY against springs, drag and cold gas, identical axes | numpy + `astro.py` | nothing; replaces the headline ratio | RUN 2026-08-10: seven of seven. 7.52x the lifetime extension of the fastest spring against 6.56x on velocity; mass parity at 1.062; cold gas wins at 3U by 7.5x, declared as a loss in advance. RE-RUN 2026-08-14 at the corrected operating point (P53): still seven of seven, at 7.33x, 6.41x, parity 1.062 and 8.3x |
| A22 | Retention gate resize against the random-vibration case | numpy + `phase1_closeout.e10` | P37, E10's analysis half | RUN 2026-08-10: six of six. 2 x D6 to 2 x D9 takes the margin at Q = 30 from −0.36 to +0.45 and keeps it positive across Q = 10-30, for 11 g |
| A23 | Tip-off at release, modelled rather than bounded | numpy rigid body | advances E7; opened P41 | RUN 2026-08-10: release is comfortable, it happens 12.2 ms into coast at zero force. The payload arrives in its cradle at 36-231 °/s, 18-115x the band, and nothing had modelled it |
| A24 | The payload ladder as a fixed-cell design, not a volume ratio | numpy + `payload_family.py` | ADR-025; opened P44 | RUN 2026-08-10: five of six, band 6 FAIL. 1U no longer closes kill criterion 1 (36/load, 2.125 kg, not 40/1.913); ThinSat and 12U do not fit at all, the 166 mm cassette width is a constraint written nowhere else. Band 6 missed at 0.508 % against 0.5 %: 720 ChipSats need 7.19 kg of shim hardware for 3.6 kg of payload |
| A25 | A flywheel energy store against P26 | numpy + `motor_model.py` | targets P26; opened P45 | RUN 2026-08-10: five of six, band 4 FAIL by 1.1 kg. Band 6, the point of the exercise, passes decisively: 35 mΩ against A10's 68 mΩ ceiling, 66 kW deliverable against 32.5 required. Needs no architecture change. Mass parity, not saving; the miss turns on one unsourced machine specific-mass figure |
| A2 | The 3-D field, and the depth assumption inside K<sub>t</sub> | numpy + magpylib | closes E1's 3-D half; opened P46 | RUN 2026-08-10: four of four run, band 4 (getdp FEM) NOT RUN so E2 stays open. The field was never 2-D, the *thrust integral* was. Resolving depth costs 4.42 % of K<sub>t</sub> (10.5386 to 10.5386), v_exit 16.029 to 16.029. Baseline not changed; computed and held. Band 1 caught a 57 % normalisation bug in the analysis; band 3 was badly chosen and measures numerical cancellation at 10⁻²⁰ T |
| A27 | Why a linear motor, and not a screw, rack or spring | numpy + `motor_model.py` | answers review item 18 | RUN 2026-08-10: screw disqualified by kinematics (49,164 rpm; DN 8.2x over, critical speed 37x under); rack fails on vacuum contact at 16.0 m/s; a ~1.8 kg spring works at 21.1 g and fails only on commandability. The motor is chosen for commandability, not performance |
| A35 | Every kilogram attributed to the requirement that causes it | `mass_properties.py`, no new physics | nothing; quantifies whether kill criterion 1 is reachable at all | RUN 2026-08-14: seven of seven. Energy arriving during the shot is the largest single driver at 28.1 %; an unmodified satellite costs nothing, which calibrates against the sibling repository's negative result. The lattice saturates at 29.94 %: 88.67 kg survives every deletion in every combination, 7.39 kg per satellite, so no architecture change closes kill criterion 1. *(The run sheet still prints the pre-A46 49.23 kg / 4.10 kg pair, P95.)* The prediction of >40 % for the pulse alone was wrong |
| A36 | Magazine density, the only lever A35 left on kill criterion 1 | numpy-free, `constraint_ledger.py` | opened P59 | RUN 2026-08-14: six of seven, band 4 FAIL. The N to ∞ limit is a healthy 0.954 kg/satellite, but 2.0 kg is first reached at N = 116, which no factorisation packages inside the track length. Largest that fits is N = 126 at 1.941 kg/sat on a 244.6 kg machine, 42-hour campaign. At N = 24 it is 4.330 kg, not the 2.05 estimated from A35 by naive division |
| A37 | The stage as the deployer, and A35's falsification test | numpy-free, `constraint_ledger.py` | advances P59; opened P60 | RUN 2026-08-14: six of eight, bands 4 and 8 FAIL. Of 126.56 kg, 29.75 is deleted by historical study physics, 43.33 is stage structure and 11.45 kg is added, all of it containment. Added mass per satellite is 1.608 kg on a small kick-stage class, so kill criterion 1 closes at 3U, with dry mass per satellite still crossing at 7.044 and both reported together. The store scales as v² and reaches 78.5 % of added mass at 8 m, so the binding constraint moves from mass to energy storage |
| A38 | Does A34's cradle closure survive the historical study operating point? | numpy-free, imports `cradle_restitution.py` | advances kill criterion 4; opened P61 | RUN 2026-08-14: five of six, band 1 FAIL. At 2.4x the offset moment the closure improves, settling 17.69 ms of 133.3 against 27.88 of 150.1, critical restitution 0.9462, residual still exactly zero. Tip-off's ceiling is 30.9 g, above the 25 g cap, so it does not bind and A37's window stands. Cost is preload, 81 to 202 N per contact. Band 1 caught A34's recorded figures being stale by 2.3 % against its own script |
| A39 | The energy store at metre-scale strokes | numpy-free | closed P60; settles A35's falsifier | RUN 2026-08-14: seven of seven. At 32.7 m/s a steel spring is 11.41 kg and busts the budget at 34.3 m/s; cold gas is 2.98 kg and busts it at 89.4, on a 1.71 L bottle for all twelve shots. Not energy density, a spring must be cocked twelve times and gas does not. A35's falsifier passes: 2.98 kg against 14.26. The binding constraint on velocity moves from mass to stroke length |
| A40 | The blowdown transient, and how velocity is commanded | numpy-free | opened P63; amends ADR-032 | RUN 2026-08-14: three of eight, bands 1, 3, 6, 7, 8 FAIL. A fixed orifice cannot hold force over a 2.18 m stroke, 4.7 g mean delivered against 25 needed, 14.16 m/s against a 30 m/s band. Flow area was never the problem (0.71 mm against a 10 mm limit); a fixed area cannot track a growing volume. A39's 2.98 kg assumed a regulator it never named. What survives: one 1.71 L bottle does run twelve shots at 4.5 % droop. Band 1 was a declaration error and is recorded as one |
| A41 | The pre-charged chamber: charge slowly, fire as a closed expansion | numpy-free | closed P63; specifies historical study's store | RUN 2026-08-14: eight of eight. A 2 L chamber at 50 bar gives 30.54 m/s at 25 g on a 4.66 kg store, no regulator, no flow-rate problem. Added mass per satellite 1.343 kg against A37's 1.608, at a higher velocity. Velocity commanded by charge pressure at 0.499 % per 1 % against valve timing at 10.53 % per ms. All three stated predictions were wrong, on a run where every band passed |
| A42 | The fill window, and the gas a bottle cannot give back | numpy-free | opened P64; answers ADR-032's falsifier | RUN 2026-08-14: five of six, band 3 FAIL. Filling is 4.14 s through a 1 mm orifice and is not the constraint. A41's 6 L bottle runs out at shot seven of twelve, below the charge pressure it cannot fill a 50 bar chamber. Correction is bounded: 7.65 L isothermal, 11.25 L adiabatic, added mass per satellite 1.344-1.455 kg. The first prediction written before its run that held |
| A15 | A twelve-satellite campaign from POEM, propagated in GMAT | GMAT 2022a | P31, and it falsified an invariance claim in the paper's own abstract | RUN 2026-08-06, three cases. Band 4's prediction was wrong by 28x and band 6's coarse number by 5.7x, both corrected in place with the wrong values kept. R3 reaches 0.7315 deg against a 0.75 deg limit. P16's lifetime invariance is withdrawn and the ratio is quoted at a stated activity level |
| A21-R | Release timing as the free baseline for phase, and what survives it | numpy-free | reads A21's comparator claim against a baseline it never set | RUN 2026-08-14: six of six. *The published claim does not survive; the design does.* Phase separation is available from release timing alone, so the schedulability argument stands and the differential-velocity argument as published does not |
| A28 | The velocity loop, designed and tested for stability rather than assumed | python-control | P47, and it is why ADR-027 exists | RUN 2026-08-13: **four of six bands fail, and the published gain is unstable.** Bands 2, 3 and 5 were flagged in advance as able to fail and did, and band 4 failed unflagged. The loop is redesigned against margins rather than tuned |
| A29 | What air costs a ground test of exit velocity | OpenFOAM | the ground-test plan, before it is written rather than after | RUN 2026-08-13: the correction is 5.1 mm/s and two bands fail. Bands 3 and 4 point in opposite directions on tunnel size, which is the useful result: the test is not free and it is not impossible |
| A30 | Can an induction drive couple to what the satellite already has | numpy-free | PII-16, and rejects it | RUN 2026-08-13: **the rail is 22x too narrow and the drive is fine.** The entry criterion for PII-16 is not met at any pole pitch, so the architecture is rejected on geometry rather than on electromagnetics. Band 2 caught a bug in this analysis, which is why band 2 was declared |
| A31 | Does the plate stay in the gap | numpy-free | the plate drive's alignment question | RUN 2026-08-13: **it centres itself, and A30's thrust was 4.4x optimistic.** The restoring behaviour is decisive in the plate drive's favour and the thrust figure that motivated it is not |
| A32 | The entry transient and segment handover | numpy-free | the last band with a plausible chance of killing the plate drive | RUN 2026-08-13: **entry is a non-event; the segment joint is not.** Two independent models agree on entry. The handover across a segment boundary is where the remaining risk sits |
| A33 | The track's dynamic case | numpy-free | P36 | RUN 2026-08-13: six of six, and A17 was not underestimating. Band 3 is a negative result and is reported as one |
| A34 | Does the rattle settle before release | numpy-free | kill criterion 4 | RUN 2026-08-13: **it settles in 27 ms of a 146 ms stroke and leaves at zero.** The band was declared as able to fail and a failure would have been a design result; it passed |
| A45-R | The stage credit, re-read after the enclosure was itemised | numpy-free | re-reads A45 | RUN 2026-08-16: four of eight. Itemising the enclosure did not rescue the credit |
| A66 | What the drive tube costs the trim stator | numpy-free | P92, and opens P117 and P118 | RUN 2026-08-30: bands 1R, 4, 5 and 6 pass, 3 fails. The wall is 0.314 skin depths and still takes 19 % of the field, because the sheet magnetic Reynolds number decides it and the tube never moves. Band 1 as first declared could not have been passed by correct code and is withdrawn under ADR-037, with the failed run preserved at `af526a0`. The run then found that the wall takes more force than the stator makes above an air-gap field of 0.1500 T |
| A67 | The payload's guided contact state through the 8 m bore | numpy + scipy | P103, P108 | RUN 2026-08-22: six of nine. Bands 3, 5 and 7 fail and band 5 is the result: historical study misses the tip-off band by 7.4x |
| A68 | The contact law, verified, and the model-form uncertainty it carries | numpy-free | the contact law A67 assumed | RUN 2026-08-22: six of seven. Band 6 fails and it is the result: the model-form spread is 65.8 %. P111 corrected an attribution this run made to a paper that does not contain the relation |
| A69 | What shape the 8 m drive tube is actually in | scikit-fem | the centreline A67 assumed straight | RUN 2026-08-22: eight of eight. At 0 g the tube's own weight contributes exactly zero and thermal bow dominates. P110 later corrected the centreline itself, and P115 the conditioning of the solve behind it |
| A70 | Guided contact on a derived centreline and a verified contact law | numpy + scipy | re-runs A67 on A69's shape | RUN 2026-08-22: two of six pass and four are NOT EVALUABLE. *That is not a pass and it is not reported as one.* P110 then found the committed results file still holding the superseded numbers, which is why the freshness gate exists |
| A71 | A numerically converged guided-contact solution | numpy + scipy | the convergence A70 could not show | RUN 2026-08-22: two pass, three fail, three not evaluable. *The run did not converge, and that is the finding rather than a reason to withhold it* |
| A72 | How long a magnet array the shot can afford to carry | numpy-free, importing `precharged` and `tube_shielding` | the closable half of P118 | RUN 2026-08-30: bands 1 and 5 pass, 3R and 4R fail at every field by 6.8x to 44.7x. Bands 3 and 4 as first declared could not discriminate and were withdrawn **before the script existed**, which is ADR-037's rule applied early rather than late. At the array length the trim force needs, the eddy drag takes 71 % of shot work and the carriage leaves an 8.0 m tube at 0.47 to 3.30 m/s against an adopted 29.01 |
| A73 | The trim secondary derived for the annulus it is actually drawn as | magpylib, through `motor_model`'s own Lorentz integral | P117 | RUN 2026-08-30: band 1 passes on all three clauses, bands 3, 4 and 5 fail. The generalised integral reproduces `motor_model`'s own 10.5386 N per kA/m with a relative difference of exactly zero, and the curved model reproduces a flat array to 0.463 % at twenty wavelengths of radius. The section as drawn makes **56.91 N against the 948.0 N in `cad/parameters.json`**, 6.00 %, short by 16.7x -- 4.02x of it the interaction surface and 4.14x the fact that Gen5's winding lies between two arrays while historical study's lies entirely outside one. Reaching 948.0 N needs 2399 mm of array against a 12.0 mm drawn piston |
| A74 | What the tube has to become, stated as a requirement rather than a material | numpy-free, importing `tube_shielding` and `array_drag` | the part of P92 that is a calculation | RUN 2026-08-31: band 1 passes by identity at exactly 0.0, bands 3 and 4 fail. **The tube's sheet conductance must fall to 657.2 S at the remanence and 4350.7 S at 0.20 T, 1.878 % to 12.430 % of the 1.0 mm aluminium wall's 35 000 S.** A liner needs 15.01 mm inside a 7.9025 mm bore radius and fits at two of six fields; thinning the aluminium needs 18.8 um against the 160 um the gas alone requires, 8.5x below it. So all three of P92's original candidates are gone and the material has to change or ADR-033 has to yield. No material is named: E11 owns the search against the number |
| A75 | Whether the decay model is the wrong shape or just at the wrong level | numpy, importing `astro` | the calculable half of P79 | RUN 2026-08-31: six of six. **E28's two GMAT reentries invert to uniform density scales of 1.9667 and 2.4443, agreeing to 1.2428x**, so one scalar explains both and `astro.py`'s piecewise-exponential shape was never the problem -- A50 published it at mean activity, x1.0, without saying so. Checked against evidence it was not fitted to: at the calibrated band 450 km lives 195.1 to 242.5 days against the 90 it survived. Re-quoted, 400 km is **77.5 to 96.3 days**, which straddles the 90-day campaign this project quotes. The 1.2428x residual is real, is probably inclination, and is what a variable-density atmosphere would explain |
| A76 | Whether inclination through a variable atmosphere explains A75's residual | `pymsis` NRLMSISE-00, numpy around it | the named candidate in P79's residual | RUN 2026-09-15: bands 1, 3 and 6 pass, band 4 fails. **Inclination gives 1.0138x where A75's residual is 1.2428x**, the right sign and 6.3 % of it in log terms, short by 15.9x. Latitude carries almost all of that and the J2 nodal rate contributes 1.0002x. The point-wise latitude contrast is 1.109x to 1.345x, ample to explain the residual, but the gradient reverses sign with local solar time and orbit-averaging removes it. A first run that aliased its own sampling against the diurnal cycle is preserved at `f65eab3`; correcting it moved the answer by 0.0001. **P79's residual now has no named cause** |
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

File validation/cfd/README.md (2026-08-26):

# A29: the ground-test air correction

The machine flies in vacuum. The test happens in a room. Every velocity in this repository
is computed with no aerodynamic drag, and the TRL-5 step in
[`../../docs/QUALIFICATION_PLAN.md`](../../docs/QUALIFICATION_PLAN.md) fires a mass simulator
down a full 1.5 m track at sea level. Nothing said what the air was worth.

Bands are declared in [`../A29_ground_test_air_drag.md`](../A29_ground_test_air_drag.md), committed
at `949fdf4` before this directory existed.

## Running it

```
python3 build_case.py              # writes free/ and channel/ from cad/stl + motor_model
python3 build_case.py --fine       # writes free_fine/ and channel_fine/
./run.sh free                      # blockMesh, snappyHexMesh, decomposePar, simpleFoam
./continue.sh free 400 40          # 400 more iterations, writing every 40, for the average
python3 forces.py free             # drag at the latest time
python3 evaluate.py                # the bands, and the ground-test correction
python3 report.py                  # figures/A29_cfd_report.png
```

`source /usr/share/openfoam/etc/bashrc` first, or use `run.sh`, which does it.

## What is committed and what is not

Committed: the generators, the force integrator, the evaluation, the report figure and the
result JSON. Not committed: the case directories. They are a function of `build_case.py`,
`cad/stl/*.stl` and `analysis/motor_model.py`, all of which are committed, so storing them would
be storing an output of a committed input, the same reasoning that keeps `cad/` deriving rather
than pasting (ADR-015) and that governs `validation/fem3d/`.

## Four things that had to be got right

1. The geometry is the CAD, not a box. `snappyHexMesh` meshes
   `cad/stl/VOLLEY_Sled_Gen5.stl` and `VOLLEY_Payload_3U_Gen5.stl` as generated. The meshed
   wetted area is 0.4173 m² against 0.5612 m² of raw STL surface, the difference is the
   payload, sled interface, which is interior and correctly not wetted.
2. The drag force is integrated here, not read from a function object. This OpenFOAM build
   aborts `forceCoeffs` with an IOstream error before the first iteration. `forces.py` integrates
   `F = ρ Σ p Sf` over the body patch from `constant/polyMesh` and the solved field instead, which
   is a better position: every step between the solve and the coefficient is inspectable.
3. The sign convention, which was wrong first. OpenFOAM boundary normals point out of the
   *fluid*, i.e. into the body, so the body's own outward normal is `-Sf` and the force is
   `+Σ p Sf`. The first attempt used the other sign and returned a negative drag.
   `forces.py` now asserts that drag is positive, because a bluff body in a uniform stream does
   not produce thrust.
4. The work integral is over a profile, not a constant force. The shot is
   position-scheduled, `v = v_target·√(x/L)`, so `v²` is linear in `x` and the drag force is too.
   The work is `F_max·L/2`. Taking `F_max·L` would double the answer.

## Two things this reports rather than hides

The solve does not converge, and it is not supposed to. A steady solver on a massively
separated bluff-body wake plateaus and oscillates; the velocity residuals sit near 10⁻² rather
than falling. The drag is therefore averaged over a window of written iterations, and the
spread across that window is quoted with the mean. Reading a single iteration would report a
sample of the oscillation as though it were an answer.

Viscous drag is bounded, not solved. `wallShearStress` aborts in this build for the same
reason `forceCoeffs` does. Rather than reconstruct a wall shear stress from cell-centre gradients,
a second, weaker solve dressed as a first, the viscous term is a turbulent flat-plate
correlation over the wetted area, and it is labelled as a bound everywhere it is quoted. For a
massively separated bluff body it is a small fraction of the total, and the pressure term, which
dominates, is solved.

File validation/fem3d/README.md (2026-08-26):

# A2 band 4: the independent 3-D solve

**The one band in [`../A2_field_3d.md`](../A2_field_3d.md) that was declared and not run.**

`E2` objects that this project's field model has only ever been checked *analytic against
analytic*, a closed-form wave model against magpylib, "neither solving a field equation". This
directory is the answer: a meshed 3-D magnetostatic PDE solve, compared against magpylib on
identical geometry.

## Running it

```
python3 build_mesh.py     # gmsh: 3 wavelengths, both arrays, in an air box
python3 make_pro.py       # generates halbach3d.pro from magnetisation.json
getdp halbach3d.pro -msh halbach3d.msh -solve Sol -pos Line
python3 compare_band4.py  # the band 4 comparison
```

## What is committed and what is not

Committed: the generators, the generated `.pro`, `magnetisation.json`, and the result.
Not committed: `halbach3d.msh` (109 MB) and the getdp working files. They are a function of
`build_mesh.py` and `analysis/motor_model.py`, both of which are committed, so storing them would
be storing an output of a committed input, the same reasoning that keeps `cad/` deriving rather
than pasting (ADR-015).

## Three things that had to be got right

1. Geometry is imported from `motor_model`, never re-entered, so the FEM and the analytic
   model cannot describe different machines.
2. μ_r = 1 throughout, which is what magpylib assumes. The comparison is therefore between
   two *methods*, not between two material models.
3. Magnetisation is derived from each block's centroid, not from its position in a sorted
   list. Both arrays occupy the same x positions, so ordering by x alone pairs them ambiguously
   and would have given one array the other's pattern.

## The bug that made the first solve wrong, and reported success anyway

The first run converged cleanly and returned a field of exactly zero at every sampled point.
The solver reported no error at any stage; the residual fell from 150.2 to 4e-13; the log was
clean. Two probes located it:

| Probe | phi |
|---|---:|
| in the air gap | **0** |
| inside a magnet | **1470.69** |

A potential that is nonzero in the magnets and identically zero in the air is not a plausible
field. `gmsh.model.getBoundary()` on the air volume returns the six outer box faces *and* every
magnet-air interface, twenty-four magnets' worth of internal surfaces. Tagging all of them as
`Outer` pinned `phi = 0` on every magnet surface, and since the air carries no source, `phi` is
then identically zero throughout the air by uniqueness. The solver was solving exactly the
problem it was given, and the problem was wrong.

The fix selects only the faces whose bounding boxes lie on the air box extremes, and asserts
that exactly six are found, so a geometry change fails loudly instead of silently returning a
zero field again.

What caught it was checking the value against physical expectation, midgap should be of
order 0.7 T, and 0.00000 is not a small number, it is a wrong one. Nothing in the toolchain
objected. This is the same reasoning as the acceptance bands: a run completing is not a run being
right.

## Two environment traps

- The packaged getdp 3.2.0 is built without Gmsh support and cannot read MSH4. `build_mesh.py`
  writes MSH 2.2 for this reason.
- A uniform mesh fine enough for the gap fills the whole air box. Refinement is confined to a
  box around the arrays; without it the mesh came out at 3,305 nodes, far too coarse to resolve
  the field it exists to measure.

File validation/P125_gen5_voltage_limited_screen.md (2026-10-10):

# P125 — voltage and current feasibility screen

**Conditional numerical screen, not a selected motor, rated speed or hardware validation.**

P118's position force map is scaled by phase current. A balanced three-phase
power identity gives `E_peak = Fv/(1.5 I_peak)`. At each time step the model
caps the current where `sqrt((E+RI)^2+(ωLI)^2)` reaches `Vdc/√3`, and
integrates capacitor droop and ESR. The resistance, inductance and peak current
come from the historical periodic-winding calculation; they are **not selected parts**.
Ideal space-vector modulation and instantaneous q-axis current are assumed.

| Surrogate case | Exit speed (m/s) | Cap draw (J) | Steps voltage limited / failure |
|:--|--:|--:|--:|
| reference unselected | 12.448 | 2149 | 0.0% |
| twice resistance | 12.448 | 3169 | 0.0% |
| twice inductance | 12.448 | 2149 | 0.0% |
| half current limit | 8.802 | 949 | 0.0% |
| half source voltage | 10.794 | 1796 | 37.0% |
| legacy commercial low esr | **fails at 0.612 m** | — | source power limit |
| legacy commercial high esr | **fails at 0.160 m** | — | source power limit |
| two parallel low esr | 12.448 | 2340 | 0.0% |
| three parallel high esr | 12.448 | 2357 | 0.0% |

The 116–185 mΩ source range is an **older distributor-data bound**, not a
manufacturer-qualified cell selection; see `validation/A10_bank_esr.md`.
The model solves the source power quadratic at each step and reports failure
when demanded terminal power exceeds `Vcap²/(4 ESR)`. Source ESR and
capacitance are varied independently here; an actual cell string couples them.

The two- and three-parallel-string branches scale capacitance and divide
ESR together as ideal identical strings. They also multiply cell count and
source mass; busbars, balancing, current limits and actual cell ratings are
unselected. A completed numerical branch is not a buildable bank.

Reference step refinement (0.2–0.05 ms) changes exit speed by at most 0.0000 m/s.
Reference energy-ledger residual is -0.0280 J.
This step check does not cover force-map interpolation, winding tolerance or source uncertainty.

P125 conditional voltage screen

The decisive motor gate remains open: select and document a winding, switching
stage and pulse source, then run switched-current and thermal cases against
their data-sheet limits. Voltage-limited speed here is an engineering sensitivity
to *assumed* components. No release speed or command precision is established.

Reproduce with `python3 analysis/gen5_voltage_limited_screen.py`; `--check`
compares the committed JSON, report and SVG byte for byte.

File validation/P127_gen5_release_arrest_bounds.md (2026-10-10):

# P127 — ideal finite-force release and arrest bounds

**Necessary momentum and energy screen only. No brake, host or payload qualification.**

P118's ideal 12.448 m/s speed and the 9.445 kg CAD-derived sled
imply 731.8 J of sled kinetic energy and 117.6 N·s
of sled arrest impulse, if no regeneration is credited. Twelve identical shots
would put 8781.8 J into arrest pathways before cooling or
energy recovery. This does not establish where heat is deposited.

The provisional CAD brake runs from 1530 to 1740 mm
(210 mm). Required **mean** force and deceleration are:

| Effective stop corridor | Length (mm) | Mean force (N) | Mean deceleration (g) |
|:--|--:|--:|--:|
| provisional brake full length | 210.0 | 3485 | 37.6 |
| half length effective | 105.0 | 6970 | 75.2 |
| quarter length effective | 52.5 | 13939 | 150.5 |

At the provisional 200 g sled cap, constant deceleration
would need at least 39.5 mm. A mean below 200 g cannot prove
a peak below 200 g: eddy entry, speed dependence, mechanical stop and
compliance must be solved on the same CAD revision.

For the declared 484.600 kg first-shot reference mass, a fixed-frame
momentum screen gives 0.345 m/s host reaction during
payload-plus-sled acceleration, 0.243 m/s recovery during
sled arrest, and 0.103 m/s net from payload departure.
This is neither an orbit prediction nor an attitude/stability analysis;
mounting lever arm, host inertia, release contact and host control are omitted.

P127 mean brake-load bounds

Reproduce with `python3 analysis/gen5_release_arrest_bounds.py`; `--check`
compares JSON, report and figure. The source hashes bind the calculation
to the committed P118 result, CAD brake dimensions and mass ledger.

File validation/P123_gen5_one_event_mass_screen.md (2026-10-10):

# P123 — one-event installed mass and fuel screen

**Status:** deterministic reference calculation; source and CI check published. This is a one-release algebra screen, not a twelve-release campaign, selected motor rating, launch-mass estimate, provider quotation or hardware validation.

## Review question

Does the propellant saved by an ideal finite-force Gen5 release offset the larger installed device in the existing matched reference case? P123 follows [the matched mission definition](../docs/MATCHED_MISSION_REFERENCE.md) and propagates the five [P122 geometry scenarios](P122_gen5_finite_force_sensitivity.md) through the same ideal preburn calculation. Run `python3 analysis/gen5_one_event_mass_screen.py --check`; plain invocation prints the full numerical result as JSON. The code uses Python's standard library.

## Controlled inputs and equation

All cases carry twelve 4 kg spacecraft on a 300 kg base host at the reference epoch. The host is assigned an illustrative 220 s specific impulse, 10 kg fixed fuel and a 2 kg reserve. The inertial target increment is **+16.029 m/s**, retained as the common mission comparison target; it is **not** a validated Gen5 release speed. Spring release is an assumed 2.5 m/s with 72 kg installed dispenser mass. Gen5 uses 126.562 kg modeled dry mass and P118's 12.448437 m/s **ideal work-to-speed conversion**, not a voltage-limited achievable rating.

For device mass `D`, fuel loaded `F`, one payload mass `p`, relative release conversion `v`, and preburn `b`, let `M0 = 300 + D + 12p + F` kg and `Ve = 220 × 9.80665` m/s. The root solve enforces

```text
b + [1 - p / (M0 exp(-b/Ve))] v = 16.029 m/s
propellant_used = M0 [1 - exp(-b/Ve)]
```

The bracketed term follows the reference model's ideal recoil bookkeeping. The fixed-fuel comparison holds `F = 10 kg`. A second, hypothetical *one-event resized-fuel* calculation solves the nested identity `F = 2 kg reserve + propellant_used(D, v, F)`. This accounts for fuel mass changing the preburn mass. The resized result cannot be used to size fuel for all twelve releases or to infer a provider launch-mass saving.

## Result

| Option | Fixed 10 kg load: one-event fuel used | Hypothetical resized one-event loaded fuel | Device + resized fuel |
|:--|--:|--:|--:|
| Spring class, 2.5 m/s | 2.692639 kg | 4.659253 kg | 76.659253 kg |
| Gen5 finite ideal, 12.448437 m/s | 0.826601 kg | 2.814686 kg | 129.376686 kg |

The fixed-fuel Gen5 case saves **1.866038 kg of propellant for this single ideal event**. The Gen5 device is **54.562 kg** heavier. With the one-event fuel load resized self-consistently, its *device plus required fuel* proxy is **52.717433 kg** higher than the spring reference. On this narrow proxy, a Gen5 device would need mass at or below **73.931985 kg** for parity at the P118 ideal speed. This is a conditional design threshold, not a feasible redesign claim or full mission break-even mass.

That proxy parity requires **52.630015 kg less Gen5 device dry mass**, about **41.6%** of the current 126.562 kg model, while preserving the same ideal release conversion. The five enclosure-related entries in the existing [mass ledger](../analysis/results/mass_properties.json)—skins 32.82, frames 8.20, radiator 2.59, bay boxes 1.87 and fasteners 4.55 kg—sum to **50.03 kg**. Even the physically impossible act of removing all five would miss this narrow parity target by about **2.60 kg** before the structure, radiator, interfaces or drive are replaced. This is an arithmetic lower-bound warning, not a proposed design. A feasible mass trade must involve multiple subsystems and rerun the force, thermal, stiffness, containment and host-interface models as their masses and shapes change.

There is also a **speed-independent lower bound** for this one-event reference. Even if an ideal release made the host preburn zero, loaded fuel could not fall below the common 2 kg reserve. Spring device plus resized fuel is 76.659253 kg, so any Gen5 device would need to weigh at most **74.659253 kg** to tie that proxy. The current 126.562 kg device misses even this physically generous limit by **51.902747 kg**. More thrust or better switching alone cannot erase this specific mass gap; the architecture or the mission value must change. This bound does not apply to a different target or complete campaign.

| P122 ideal geometry case | Ideal conversion | Gen5 one-event resized fuel | Gen5 minus spring device + fuel |
|:--|--:|--:|--:|
| Nominal 12 mm gap | 12.448438 m/s | 2.814686 kg | +52.717433 kg |
| Gap 14 mm | 11.613728 m/s | 2.997865 kg | +52.900612 kg |
| Gap 16 mm | 10.840040 m/s | 3.167715 kg | +53.070463 kg |
| Depth offset 5 mm | 12.202757 m/s | 2.868594 kg | +52.771341 kg |
| Depth offset 10 mm | 11.957672 m/s | 2.922377 kg | +52.825124 kg |

The tiny difference between P118's nominal 12.448437 m/s and P122's 12.448438 m/s is their separate numerical integrations. It has no physical meaning at this precision. All table speeds are ideal energy conversions and are **not** commanded or guaranteed releases. The five cases are selected perturbations, not a probability distribution.

P123 device and one-event resized-fuel comparison
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

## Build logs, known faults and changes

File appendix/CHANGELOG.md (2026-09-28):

# Change log / audit record

## 2026-09-16: combined errors, reference-cell mechanics and review surfaces

I declared P113-S6 and P92-S2 in f0026a7 before implementing or executing them. S6 retains
512 conditional release-error corners. The illustrative base box passes both events, while
doubling its widths fails 20 of 64 first-event corners. Each event starts at its nominal host
state; this is not robust campaign closure. P92-S2 retains 144 linear-spring/pusher cases;
48 meet the analytical 10 g/contact screen. A zero-end-preload spring requires twice the
constant-force ideal stroke in the frictionless limiting case.

S5 freshness now compares computed event data with declared numerical reproduction floors,
retains exact sources/verdicts and regenerates presentations from the stored payload. Its
physical verification bands are unchanged. The local gate now includes S5 as CI already did.
The optional CAD runtime is pinned to the documented CadQuery 2.8.0 generation; a local
2.7.0 kernel produced different package bytes and is not used to certify artifact identity.

I recovered the useful PR36 fault-topology/burden accounting without restoring its superseded
architecture disposition. The new verification matrix records model credibility limits and
missing mission, cell and host questions. P92, P113 and E5 remain open.

Public updates repair the deployed website's out-of-root figure and document paths, add the
new studies and BOLLEY's visual review page, and synchronize the profile with the current reference.

## 2026-09-15: A76 falsifies the cause P79 named for its own residual

A75 left a 1.2428x residual between E28's two GMAT reentries, and P79 recorded the candidate in
writing: "inclination is the obvious candidate, and that is the part a variable-density atmosphere
would explain." A76 tested that sentence and it is wrong.

The premise checks out. `build_poem_campaign.py` sets R2 and R3 at the same altitude,
eccentricity, epoch, atmosphere, F10.7 and Kp, differing in `INC_DEG` alone, so inclination is the
only route a variable atmosphere has. There are two of them and A76 separated them.

| | |
|---|---:|
| Inclination delivers, NRLMSISE-00 at 350 km and the run's own indices | 1.0138x |
| A75's residual needs | 1.2428x |
| In log terms | 6.3 %, short by 15.9x |
| Of that 1.0138, from the J2 nodal rate | 1.0002x |

Bands 1, 3 and 6 pass; band 4, the one the run exists to ask, fails. The direction is right and
holds at all four quarters, so the mechanism is real and its size is not within a factor of fifteen
of the job.

**Why it is small, which the point-wise numbers do not suggest.** At fixed UT the model's latitude
contrast is 1.109x to 1.345x, ample. It does not survive because the gradient reverses sign with
local solar time, rising towards the pole on the night side and falling on the day side, so an
orbit sampling every local time averages it away. Recorded as a labelled post-hoc diagnostic that
no band depends on.

**The run's own first execution was faulted and is preserved at `f65eab3`.** It sampled two
revolutions per day, which put its step at exactly 43 200 s against a diurnal cycle and pinned the
grid to a fixed pair of local solar times, so band 5 read local-time sampling at 1.0004x, which is
what a blind grid reports rather than what the atmosphere does. The grid now walks every
revolution contiguously, 452 over 29 days at 24 points each. Correcting it moved band 4's answer
by 0.0001. The defect was real and it was not what made the band fail.

Bands were frozen at `94122ba` before `analysis/inclination_density.py` existed, and
`git show --stat 94122ba -- analysis/inclination_density.py` returns nothing. Bands 1 and 6 check
tooling and were deliberately run first; bands 3 and 4 were not evaluated in any form before the
declaration was committed.

**P79's residual now has no named cause.** What is left standing is a flag the GMAT build script
already carries beside both cases, "POEM-4-like -- UNVERIFIED" and "POEM-3-like -- UNVERIFIED":
two reference orbits not traceable to this repository, now carrying a 1.2428x disagreement with no
physics attached. That provenance is the next thing to check and it is a different kind of
question. P79's next step is re-pointed at it.

A75 is untouched, A50 band 1 stays failed, E28 stays open. `pymsis==0.13.0` is pinned in
requirements.txt and the run is in the freshness gate at a declared 1e-6, because pymsis returns
float32 and the same Fortran under another compiler cannot be held below that.

## 2026-09-15: the reading backlog is blocked by the network, not only by paywalls

P57 and E16 both need a publisher. This environment cannot reach one. `ieeexplore.ieee.org`,
`www.mdpi.com`, `arxiv.org`, `doi.org` and `api.crossref.org` all refuse with `EGRESS_BLOCKED` or a
403 from the proxy tunnel, while `pypi.org` returns 200 and git pushes succeed. Recorded as the
fourth measured limitation in `docs/REPRODUCTION_ENVIRONMENT.md`, whose previous version said "a
fourth will exist".

It is a different kind of limitation from the first three. Those made a gate fail, lie, or pass on
an eighth of the evidence. This one leaves every gate correct, because every gate here is offline
by design, and blocks work the gates were never pointed at.

**E16 narrows, on access rather than on references.** Its close condition charged all three
remaining items to publisher access. Two of them are not behind a publisher, and E16's own recorded
metadata says so: `\bibitem{eddy}` is *Actuators* under a `10.3390` DOI, which is MDPI and fully
open access, and `foster2` is arXiv:1509.03270, a free preprint. Exactly one reference genuinely
needs a subscription, `foster` in the AIAA *Journal of Spacecraft and Rockets* under
doi:10.2514/1.A33927. The reading list is the same length; the remedy for two thirds of it is any
ordinary machine.

**P57 gains a locatable citation and nothing else.** The entry named a paper by author, volume and
first page, with no title. It is *"A High Thrust Density Voice Coil Actuator With a New Structure
of Double Magnetic Circuits for CubeSat Deployers"*, IEEE Xplore document 9652065, agreeing across
two independent indexes and consistent with the volume and page the 2026-08-14 search recorded. A
DOI and an end page were offered by a generated search summary; neither is recorded, because a
summary is not one of the independent indexes E16 requires and nothing reachable from here can
check it.

No `PRIOR_ART.md` entry was written. That file records that it was first written from abstracts and
that three of its conclusions were wrong, and the paper in question is the one this project calls
its nearest published neighbour. Both entries stay LIVE; the register count is unchanged at 51.

## 2026-09-15: P56's free-baseline restatement audited surface by surface

P56 was corrected on 2026-08-14 by A21-R, and its note listed eleven public surfaces plus both
manuscripts as restated. The list was taken on trust. Checking it found twelve of the thirteen
already naming release timing at 468 s as the free baseline for in-track phase, and one that did
not.

`docs/RESULTS.md` still headed its seeding section "the actual value proposition" and priced 30°
against differential drag alone, 1.4 days against 25. The two banners at the top of that file
retire its operating-point numbers and say nothing about phase, so nothing marked the passage.
It now carries a dated correction naming the 0.0641 °/s in-track rate, 468 s to 30° at 450 km,
ADR-020's 1200 s cadence at 76.9° per shot, the 21.75 °/day drift a commanded split leaves
behind, and the +28.8 km and x1.602 that only Δv buys against x1.0000 for timing at any cadence.
The chart stays: its drag arithmetic is right, and only the comparison it implies is incomplete.

The other half of the criterion was the companion row in `analysis/comparators.py`. A21-R's R1
through R6 are present, added below A21's seven originals rather than replacing any of them, and
R2 is the row itself, time to 30° by timing over time by commanded differential, banded at
≤ 0.01. Band 3 is unedited and still reads as it passed.

With both halves met P56 classifies CORRECTED. The live register count moves from 52 to 51,
propagated to `SUMMARY.md`, `docs/CONTINUITY.md`, `docs/PROGRAMME_EXECUTION.md`,
`docs/GEN5_CLOSURE.md`, `docs/index.html`, the regenerated BSX review and the closure routing
table. No band was edited and no number moved.

## 2026-09-15: P39's provenance question answered against its own guess

P39 closed with a paragraph that guessed at its own end state: that `validation/fea/plate*.inp`
"belongs in the flagship and the solver output does not", on the strength of a sentence in
`validation/README.md` telling contributors to commit input decks. `.gitignore` had already
decided the opposite, under the comment that the decks are regenerated by
`validation/fea/build_deck.py`. The entry itself called that answering the question by accident.

Settled by measuring the generator rather than by choosing the more agreeable of the two texts.
`build_deck.py` reads three tracked files and nothing else. Run twice in the same environment it
produced byte-identical decks, 2 252 204 bytes pinned and 2 252 205 bytes clamped. Solving both
with CalculiX 2.21-1 under gmsh 4.15.2 reproduced A4's published bracket:

| Case | Reproduced | Published |
|---|---:|---:|
| pinned | 0.01945 mm | 0.0194 mm |
| clamped | 0.01600 mm | 0.0160 mm |

A deck that is a deterministic function of committed inputs carries no provenance its generator
does not already carry, so committing 4.5 MB of it buys nothing, and ADR-015's derive-never-paste
rule applies. `validation/README.md` and `docs/RELATED_WORK.md` now state the rule that way:
commit the generator where a tracked one exists, commit the deck where none does, commit result
JSON either way. What the measurement does not cover is gmsh version drift, which is why the run
sheet records mesher and solver versions beside the hashes, so a later mismatch is visible rather
than silent.

The stray files the entry was originally about were never a published copy of anything. They were
collected off a dirty working tree, which is the defect, and the `git ls-files` filter added on
2026-08-10 already prevents it.

With its last open question answered, P39 classifies CORRECTED. The live register count moves from
53 to 52, propagated to `SUMMARY.md`, `docs/CONTINUITY.md`, `docs/PROGRAMME_EXECUTION.md` and the
closure routing table. Dated audit lines in `docs/GEN5_CLOSURE.md` and the earlier
`PROGRAMME_EXECUTION.md` batch record are left at 53, because they record what was true on their
own dates. No band, no result and no Gen5 or historical study number changed.

## 2026-09-15: the public routing table misquoted eleven register titles

`docs/workstreams/ENGINEERING_CLOSURE.md` routes every live entry and quotes each native title
verbatim. Filling its owner column had been done by substitution, and the substitution reached
inside the quotes it was not supposed to touch:

| Register | Published |
|---|---|
| `An acceptance band was set ...` | `Redesignn acceptance band was set ...` |
| `At femtosat scale ...` | `Redesignt femtosat scale ...` |
| `ADR-032's first falsifier fires ...` | `RedesignDR-032's first falsifier fires ...` |
| `A65 band 4 misses A53's per-cell mass threshold ...` | `Redesign65 band 4 misses ...` |

Eleven titles across P30, P34, P44, P57, P68, P91, P94, P117, E6, E24 and E25, all restored from
`OPEN_PROBLEMS.md` rather than from any secondary copy. No status, next step, owner or count
changed; the routing still carries 53 entries.

`tools/check_routing.py` now requires every routed ID to exist in the register, its quoted title
to match that entry's heading exactly, and no ID to be routed twice. It does not check the owner
column, which is a human assignment the register has no opinion about. Wired into CI and
`verify_all.sh`, and demonstrated against a mangled title and a phantom ID.

**The gate found four of the eleven that a manual search had missed.** A pattern looking for the
substitution before a letter does not see it before a digit, which is exactly how `A65`, `A13`
and `A55` survived the first pass. That is the argument for comparing against the source rather
than searching for the symptom.

## 2026-09-15: finish the mission-study publication

- CI run 34928809087 exposed an incomplete freshness repair: scalar velocity-error
  norms and burn magnitudes still used a stricter unit-inappropriate floor than
  velocity vectors. Apply the already documented 1e-7 m/s floor to those quantities;
  retain physical acceptance, conservation checks, fuel tolerances and exact verdicts.
- Preserve the observed failures in regression tests and the incident record.
- Regenerate the mission evidence and companion snapshots after the repair, then
  verify the coherent batch before updating the main branches. Gen5 numbers,
  historical study configuration and the 53 live problem dispositions remain unchanged.

## 2026-09-15: terminal-state timing benchmark with shared comparator controls

P113-S3 declares criteria before implementation and compares three terminal circular
states over twenty release times and five assumed speed screens. Every alternative
receives the same initial and pre-release host-burn choices. Full Cartesian arrival
bands replace the energy-only criterion for this bounded single-payload benchmark.

The first independent test run rejected the circular no-transfer control. The root
unknown was changed from a near-zero correction to absolute orbital velocity, retaining
the same physical seeds, required solver success and frozen boundary residual. The
initial failed test is published with the run sheet. A best result on the latest-time
boundary does not establish an interior or global optimum. P113 and E5 remain open.

## 2026-09-14: sequential campaign allocation and architecture decision gates

P113-S2 declares criteria before implementation, then compares 180 prescribed
orbital-energy campaigns with propagated host state, changing manifest mass, burn
propellant and recoil. Fixed and adjustable spring controls remain in the comparison.
Independent Kepler propagation, event conservation, failure controls and stale-output
injection verify the bounded calculation. Complete mission feasibility is not claimed.
Implementation review replaced byte-only numerical freshness with documented tolerances
below the verification limits, retaining exact source metadata and presentation checks.

The execution record consolidates the open work and admits compact independent release
cells as a candidate alongside the magazine and gas guide. No historical study configuration,
operating envelope or provider interface is selected. P113 and E5 remain open.

## 2026-09-14: begin the host/deployer allocation trade without selecting a machine

P113-S1 declares and commits its criteria before the departure analysis exists.
The new single-event model includes finite host recoil and compares assumed release
intervals against a signed host impulse budget. Independent state reconstruction,
interval intersection and injected stale-output tests check the bounded calculation.
The speed intervals are deliberately optimistic screens, not validated operating
envelopes. No new hardware capability or full-mission resource advantage is claimed.

`docs/HOST_COMPATIBILITY.md` separates public Skyroot/Agnikul descriptions from
unavailable interfaces, adds a packaging gate and records common-path failure
questions. No company or individual endorses this study. P113 and E5 remain open;
Gen5/historical study operating points, BOLLEY's design and existing acceptance bands are unchanged.

## 2026-09-14: what a clean environment needs, recorded because two gates lied without it

`PROTOTYPE_READINESS.md` package 0 asks for environment limitations to be recorded separately,
and package 12 asks for the release evidence to be rerun from a clean environment. Nothing
covered that. `docs/REPRODUCTION_ENVIRONMENT.md` now does, from a container reset on 2026-09-14
rather than from reading the scripts.

Three measured degradation modes, and only the first is harmless:

| Missing | Effect |
|---|---|
| `numpy` and the rest of `requirements.txt` | **Loud failure** across four gates. Nobody reads a traceback as a pass |
| `cadquery==2.8.0` | **False positive.** Four STEP files reported STALE that are current -- without it the artifacts gate cannot rebuild-and-compare and falls back to the commit-time comparison its own docstring calls unreliable |
| Full git history | **False clean.** The authorship gate printed a clean line over 52 of 412 commits |

`tools/env-setup.sh` now installs past the distribution-owned `packaging` -- which otherwise
aborts the entire requirements install over one conflict -- adds cadquery with a stated reason,
and unshallows the clone when it finds one. The identity section records that neither the global
nor the per-repository git identity survives a container restart, and that the only durable
control is the gate committed to the repository.

## 2026-09-14: the authorship gate passed over a truncated history and did not say so

The gate added on 2026-09-07 reported `authorship: 52 commits, every author and committer is the
repository's own` in a working container whose clone was shallow. The repository had 412. It
passed, and it passed for the wrong reason: the sentence it prints is a claim about EVERY commit,
and on a truncated history it cannot make that claim about the ones it cannot see.

`tools/check_authorship.py` now detects a shallow clone and REFUSES rather than passing, naming
the number of commits it can reach and `git fetch --unshallow` as the fix. Both paths are
demonstrated: it refuses at 52 and passes at 412 on the same clone, before and after unshallowing.
CI is unaffected, because the workflow already fetches full history for `check_companions`.

A gate that quietly checks a subset is worse than one that refuses, because it reads as a clean
result. This is the same defect class as `check_artifacts.py`'s own note that *a false positive in
a check is a defect in the check* -- a false NEGATIVE is the more dangerous half.

## 2026-09-14: isolate artifact rebuilds (P119)

I reproduced an artifact-check defect: a CAD rebuild changed the working reference and a later
comparison could report agreement with that replacement. Rebuilds now run in temporary copies,
compare the complete file set and reuse one verdict per artifact. Four injected regressions pass.
Runtime-dependent CAD differences remain failures to reproduce, not automatic geometry changes.

## 2026-09-14: current review routes and prototype completion programme

I replaced the long README with a configuration-specific review route and current Gen5/historical study
images. The previous front page remains accessible at its exact revision. I replaced the stale
BUILD_READINESS snapshot, which still described answered items such as A52's angular-impulse
calculation as absent. No physical result, acceptance band or register disposition changes.

PROTOTYPE_READINESS.md defines the intended completion programme for VOLLEY and BOLLEY:
mission requirements, model credibility, coupled dynamics/electrics, tolerances, installed
budgets, controls, manufacturing and experiment design. The packages are planned, not claimed
complete. The current audit also found the companion payloads stale after 67939b7; they must be
regenerated before this batch is published.

## 2026-09-06: register headline gate

The register's opening table still carried superseded totals while its result JSON and other
public pages carried the current counts. The table is now generated from the same classifications
as the JSON. The check also rejects an entry whose written status disagrees with its classification.
No entry or disposition changed. The dated classifier history is retained.

## 2026-09-06: A13 verdict consistency

A13 assigned its acceptance verdicts as strings, so a changed result could retain the old
verdict. Verdicts now follow the recorded peak momentum, transient rate and endpoint momentum.
The stopped rigid-body endpoint meets row 5 immediately; a nonzero endpoint is unevaluated
without a controller. Row 7 remains void. The current run still fails rows 3 and 4. No acceptance
band has changed, and no engineering item is closed by this bookkeeping correction.

The result's inertia description still named the superseded loaded mass while the calculation
read the current mass. It now reads the same source. The offline gate checks band consistency,
source identity and that mass description. Fault injections and properties exercise the original
strict boundaries, changed inputs and unavailable settling evidence. These checks do not
establish the host inertia, flexible-body behaviour or control authority.

## 2026-09-07: the single-author claim is now enforced rather than asserted

This repository states on its front page, in `CITATION.cff` and on every companion that the work
is mine. Nothing checked it, and on 2026-08-31 a sibling repository was found carrying one commit
written under a different identity. VOLLEY escaped only because its clone happened to hold a local
`user.name` override, which is luck rather than a control.

| ID | Item | Detail |
|---|---|---|
| Gate | `tools/check_authorship.py` | Every commit reachable from HEAD must carry an author **and** a committer from a two-entry allowed set spelled out in the file rather than read from `git config` -- the configuration is exactly what failed, so reading it back would test nothing. Both fields are checked, because an identity can be laundered through the committer, which a casual `git log` does not show |
| Gate | Wired into CI and `verify_all.sh`, ahead of the link check | CI fetches full history for `check_companions`, so the gate sees every commit rather than a shallow tail |
| Verification | It passes here and it catches the case it was written for | 409 commits, every author and committer clean. Run against the sibling repository's pre-repair history it names the offending commit and the identity, which is the injected-fault standard the rest of the gate set is held to |

A provenance claim nobody checks is not provenance, in the same way a band nobody computes is not
a verdict. `check_bands.py` exists for the second reason; this exists for the first.

## 2026-09-06: BSX evidence and closure audit

The full local gate found a stale README overview that CI did not check. Regenerated it and added the overview and register-derived BSX review to CI. Contributor and provenance pages still denied the existing test suite and finite-element evidence and named the superseded licence; corrected the current guidance.

A24-R closes P54 against the current mass reference while preserving A24 failures. A2-R closes P55 by re-deriving four depth-resolved constants and recomputing all ten lever rows, preserving the previous results as history. Both were separately declared before implementation at e0a3cf611824efe19d045cab4fc73dcdfaa7abca.

Reconciled P37, P46, E29 and P95 against their already-published closing evidence. These are disposition repairs, not new experiments or changed thresholds. Gen5 retains 11 computation items and three decisions. historical study retains 18 computation items. Replaced the stale state page with a current handoff and narrowed an unsupported absolute comparison with spring deployers. Historical results and manuscript content are preserved.

Every change made to this repository after the initial export is recorded here, so that
each edit can be traced to a cause and a source of truth. This file is deliberately
exhaustive: it exists to be audited later.

Read alongside `docs/PROVENANCE.md` (what stands behind each claim), `OPEN_PROBLEMS.md` (the defect
list these changes close) and `docs/DECISION_LOG.md` (why design choices were made).

---

## 2026-08-31 (sixty-fifth pass): A75 asks the cheap question first, and the decay model turns out to be the right shape at the wrong level

P79 asked for a variable-density atmosphere. Before writing one, A75 tested whether the model's
*level* explains the disagreement, and it does.

| ID | Item | Detail |
|---|---|---|
| A75 | **E28's two GMAT reentries invert to uniform density scales of 1.9667 and 2.4443** | They agree to **1.2428×** against a band that asked for a factor of two, so one scalar reproduces both. `astro.rho` already carries eleven base altitudes with their own scale heights; its shape in altitude was never in question. **What A50 published was that table at mean activity, ×1.0, and it did not say so** |
| A75 | Checked against evidence it was not fitted to | The 450 km case was a one-sided fact, not a fitting point. At the calibrated band a 450 km satellite lives **195.1 to 242.5 days** against the 90 it survived, and on its own that case would have permitted any scale up to 5.3093. A50's altitude monotonicity holds at both ends of the band |
| A75 | The headline becomes a range, which is what P79 asked for | 350 km **29.0 to 36.0 d**, 400 km **77.5 to 96.3 d**, 450 km **195.1 to 242.5 d**, 500 km 461.6 to 573.7. *"450 km buys months"* is 6.4 to 8.0 months. **The 400 km row straddles the 90-day campaign this project quotes**, which the single number could not say |
| A75 | The residual is kept rather than explained away | Two cases at the *same altitude* need *different* scales, which a scalar cannot carry by construction. Inclination is the obvious candidate. P79 stays LIVE and stays `COMPUTATION` for it: the question has shrunk from 2.4× to 1.24×, not disappeared |
| A75 | Three ways of over-reading it, closed off in the run sheet | **A50 band 1 stays failed** — it asked for ≤ 60 d and got 70.6, and a calibration after a band fails does not reach back. **P16 is not rescued** — a uniform scaling preserves a lifetime ratio by construction, which is precisely why P16 withdrew the invariance claim. **It is not a measurement** — GMAT is a second model |
| A9 | Re-tested today, and still not runnable | CelesTrak is still refused by this environment's egress proxy under organisation policy, exactly as A9 recorded when it was written. The repository still has no comparison against a flown object. E4 stands, for the same reason it did in July |
| Gate | A75 is **in** the freshness gate, and the reason is measured | `astro.lifetime` advances in `int()`-quantised chunks, the hazard that made that gate numeric in the first place. Perturbing the density scale by one, two and four ulp and the ballistic coefficient by one moved the 350 km lifetime by **exactly zero** in all four cases, so it is gated at the default tolerance rather than excluded |
| Counts | 75 run sheets, 72 analyses | Register unchanged at 153 entries, 59 live |

---

## 2026-08-31 (sixty-fourth pass): A74 states the tube as a requirement, and P92 becomes a decision

Four runs in two days have taken P92 from *nobody has computed what the tube costs* to *here is
the number the tube has to meet, and here is why no local fix meets it*.

| ID | Item | Detail |
|---|---|---|
| A74 | The requirement, and no material named | **The drive tube may carry 657.2 S at the remanence to 4350.7 S at a 0.20 T air-gap field — 1.878 % to 12.430 % of the 1.0 mm aluminium wall's 35 000 S.** At 0.60 T it is 1446.3 S, A72 band 6's number to the digit, which is two inversions of the same model meeting from opposite ends. No new material data enters the run and E11 owns the search against it |
| A74 | Band 1 is an identity, not a cross-check, and says so | The file imports `tube_shielding` and `array_drag` rather than re-deriving them, so agreement would prove nothing about the physics. What it checks is that the import is live: the break-even field and the worst force-over-parity ratio reproduce the committed values at exactly 0.0. A stale import is the failure mode this run actually has |
| A74 | **Band 3 fails and P92's third candidate goes** | A liner needs **0.59 mm at 0.20 T and 15.01 mm at the remanence** against a 7.9025 mm bore radius, fitting at two of six fields. It buys one power of `exp(-kt)` and not two, because it moves the magnets away from the winding as well as from the wall — 12.3 % per millimetre on the ratio, not 23 % |
| A74 | **Band 4 fails and the wall is not a free variable** | Thinning the aluminium alone needs **18.8 µm** against the 0.16 mm A59 says the gas alone requires — 8.5× below the pressure floor and 53× below the 1.0 mm as drawn |
| A74 | Band 5 supplies the number ADR-035 did not have | Steel is **+2.154 kg** on a shared tube, **+0.1795 kg per satellite**, taking A73's 1.6050 kg to 1.7845 kg against a 2.0 kg ceiling. ADR-035 chose aluminium on mass alone and was right on the questions asked of it. **The mass it saved is affordable to give back** |
| A74 | A band whose wording admitted two readings, recorded as such | Band 3 did not say whether the liner had to work at *some* field or at *every* field. The implementation takes the strict reading and the run sheet prints both counts, because the loose reading would pass in the corner where the secondary makes 18.37 N against a 948.0 N specification, and a band that passes where the machine makes nothing tests nothing |
| **P92** | **Moved from `COMPUTATION` to `DECISION`, and the move is argued rather than taken** | On 2026-08-30 this entry stayed `COMPUTATION` and said explicitly that relabelling it would take one off the closure count for no work. The work has since been done: four run sheets, two with failing bands, and every local fix eliminated by calculation. What is left is which of ADR-033 and ADR-035 yields, and no analysis settles that. historical study remaining COMPUTATION 19 → 18, DECISION 0 → 1, and `docs/COMPUTATIONAL_CLOSURE.md` carries the reasoning beside the count |
| Index | The gate added yesterday caught its first real omission within the hour | `check_links.py` failed on A74's run sheet having no row in `validation/README.md`, before the commit was made |
| Gate | A74 excluded from the freshness gate by name | Twelve nested root-finds over A72's own root-find over the shot integration |
| Procedure | `check_companions.py` gains the thing that keeps reddening CI | The export record can only name a commit that already exists, so it is always the commit after. Four CI runs failed on that gate in two days, each of them right, each on a push made before the export. Push once per unit of work with the export record last |

---

## 2026-08-30 (sixty-third pass): A73 derives the constant A55 borrowed, and the trim force is 6 % of what the parameter file says

A66 bounded it and stopped, because bounding a number is not deriving it. A73 derives it.

| ID | Item | Detail |
|---|---|---|
| A73 | The verification that makes the rest usable | The Lorentz integral `motor_model.thrust_constant()` performs is generalised to take the field and the cross-section as arguments, and handed Gen5's own flat field it returns Gen5's own constant — **10.538611491665296 against 10.538611491665296, a relative difference of exactly zero**. No phase convention, no factor of two in a time average and no normalisation is re-decided between the machine the constant was measured on and the machine it was applied to |
| A73 | The curved geometry checked against a limit, not against a second approximation | At a bore radius of twenty wavelengths the annular model reproduces a flat single-sided array to **0.463 %**, and doubling the angular sectors moves the peak field by **0.1037 %** |
| **P117** | **The section as drawn makes 56.91 N against the 948.0 N in `cad/parameters.json`** | **6.00 %, short by 16.7x.** About 4.02x is the interaction surface — 306.0 cm² of flat array against 76.03 cm² of annulus — and 4.14x is chiefly that Gen5's winding lies between two arrays while historical study's lies entirely outside one, with its outer copper where the field has fallen to 45.6 % across the 6 mm belt |
| P117 | Two failures that came with it | Reaching 948.0 N needs **2398.9 mm** of magnet array against the **12.0 mm** piston `build_legacy_study.py` draws, 200 lengths of the part it would live on. And the array is on the carriage, which ADR-035 records is not recovered — *"each of the twelve satellites has its own"* — so it is added **undivided**, unlike the shared stator section `trim_authority.py` divides by twelve: 1.6050 kg per satellite as drawn, 6.44 kg at the length 948.0 N needs, against a 2.0 kg ceiling |
| A73 | Band 6, the one thing on the design's side | A convex array at this radius concentrates its own field **1.25x** over a flat array of the same depth and standoff. Reported, not banded: the difference is physical and ADR-037 forbids a tolerance on a gap of that kind. The standoff is matched exactly, because the first version of this file compared 0.6 mm against 0.5 mm and put an `exp(-k dz)` of 1.3 % inside a number whose whole purpose is to be honest about a 25 % effect |
| P117 | `cad/parameters.json` is **not** edited, and the reason is written down | Correcting `force_N` moves the section length, the peak power, the correction energy, the CAD and A55's own bands — a re-run of A55, not an edit — and A72 found the same day that the architecture it would re-size is falsified. The wrong number stays visible with P117 attached rather than quietly replaced. P92's trade first, then A55 |
| Index | `validation/README.md` was nineteen rows short and said so nowhere | It opened by describing *"nineteen of the twenty-one below"* while the directory held 73 files, and every run from A66 onward was missing. Every file now has exactly one row, and `check_links.py` gates it: a deleted row, a phantom entry and a duplicated row are each caught, demonstrated by injection. `check_public.py` counted run sheets and never checked whether they were listed |
| Gate | A73 excluded from the freshness gate by name, with the reason | Ten minutes of magpylib over 720 cylinder-segment sources |
| Runs | Two runs of A73 discarded before the one recorded | One died serialising a numpy boolean; one compared band 6 at mismatched standoffs. Neither produced a number that is used, and both are named rather than left out |
| Counts | 73 run sheets, 70 analyses. Register unchanged at 153 entries, 59 live | A73 answers an entry that was already numbered |

---

## 2026-08-30 (sixty-second pass): A72 integrates the drag A66 found, and two adopted decisions turn out to exclude each other

A66 could not integrate the brake it discovered, because the magnet array is dimensioned nowhere
in this repository. A72 makes the length the variable instead of waiting for one.

| ID | Item | Detail |
|---|---|---|
| A72 | Bands declared before the script, then two of them withdrawn before the script, then the script | `3f70082` froze six bands. `0abbe1b` withdrew bands 3 and 4 as unable to discriminate and froze 3R and 4R in their place, **with no result in existence**: band 4 could never fail, because the drag vanishes with velocity while the gas force never falls below the seal friction — 445.88 N at the breech, 198.15 N at the muzzle, against 83.4 N — so any carriage always reaches the muzzle. Band 3 failed at zero array length, because 29.01 m/s already has the whole 28.3887 % friction allowance subtracted from it. ADR-037's rule applied one run later and this time *before* the script |
| A72 | Three lengths at each field, and no favourable end of the ladder | The array that makes the section's 948.0 N is **6.8× to 44.7×** longer than the array whose drag costs what the seal friction costs, and **5.6× to 36.9×** longer than the array that stops the carriage accelerating. At the length the force needs, the eddy drag takes **71 % of shot work** and the carriage leaves an 8.0 m tube at **0.47 to 3.30 m/s** against an adopted 29.01, decelerating. A weaker magnet needs a longer array and the drag scales with the array, so the ratio gets worse as the field falls |
| A72 | Band 5 is the one that makes it hard to dismiss | Halving the conductivity, halving the wall, and doing both leave all four verdicts unchanged. The finding is not sitting on a handbook conductivity or on a wall thickness chosen for handling |
| A72 | Band 6 puts a number in P92's fix trade | The wall's sheet conductance would have to fall to **1446.3 S**, 4.132 % of the 1.0 mm aluminium wall's 35 000, or 1.4463e6 S/m at that thickness. That lands within a few per cent of austenitic stainless, which is a boundary and not a solution: A63 already priced steel at +2.154 kg, and three per cent against a handbook value at room temperature is not a margin |
| A72 | Two coding defects, found before the result was believed, neither a band | The shear check was wired to the reduced field rather than the incident one, double-counting the transmission by `1/(1+Rm²)`, 36.2 % at this point — band 1 caught it. And neither the drag energy nor the worst acceleration is monotone in array length, because the drag goes as `v·L` while `v` falls roughly as `1/L`; a plain bisection returned its own upper bound as an answer for three of six fields, and the shortest crossing is now found by scanning first |
| P118 | Integrated, and the fix handed to P92 rather than duplicated | The entry stays LIVE and stays `COMPUTATION`. What is left is the trade P92 owns, now with A72's number in it |
| Gen5 | Untouched, and the run sheet says so | The Phase I machine is a flat ironless stator with no tube and no conducting member between the winding and the array. Nothing in A72 reaches `docs/BASELINE.md` |
| Gate | A72 excluded from the freshness gate by name, with the reason | 44 s of root-finding over an integration, which is the A67 and A68 case. An exclusion that is not written down is a gap |
| Counts | 72 run sheets, 69 analyses | Register unchanged at 153 entries, 59 live: nothing here is a new defect, it is the answer to two that were already numbered |

---

## 2026-08-30 (sixty-first pass): A66 runs, and it answers a bigger question than it was asked

P92 asked what the aluminium drive tube costs the trim stator. The answer to that is 19 % of
authority, and 34 mm more section buys it back. Then the same model said something the bands
were not written to catch.

| ID | Item | Detail |
|---|---|---|
| A66 | The run, preserved with its faults before any of them were corrected | `af526a0` is the run as it executed against the bands frozen in `e05551b`. It failed band 1 at 1.4874 % against 0.5 % and band 3 at 0.9356 m/s against 1.1543, and its loss model was wrong by a factor of two. Nothing about it was cleaned up |
| ADR-037 | Band 1 could not have been passed by any correct implementation, so it is withdrawn rather than widened | Holding the sheet conductance fixed and shrinking the wall, the slab converges on the sheet at exactly first order across three decades — 1.487 % at 1.0 mm, 0.001581 % at 0.001 mm. Both routes are therefore right, and 1.4874 % is the thin-sheet truncation error at `kd` = 0.131. A 0.5 % tolerance sat underneath a number the geometry fixes. The declared row is not edited |
| A66 | Band 1R, frozen in its own commit before the script was touched again | Limits and convergence order rather than the size of a cross-method gap: zero-σ transmission exactly unity and exactly `exp(-kd)`, agreement within 0.01 % at a 1e-3 mm wall, and every pairwise convergence order first order to within 0.05. It passes at 0.0436. It is a harder gate than the one it replaces |
| A66 | A factor of two in the loss model, found in review and not by a band | Peak-amplitude phasors dissipate `\|K\|²/(2σd)`, not `\|K\|²/(σd)`. The tell is that the faulted version implied a shear three times the Maxwell bound `B²/2μ₀`, which nothing can do. That bound is now computed on every run; the corrected result sits at 0.9906 of it, which is where a sheet at `Rm` = 0.754 belongs |
| A66 | The air-gap surface is an annulus, and I had used the flat Gen5 array's depth | 90 mm is `stator.active_width_y`, the depth of the Gen5 flat array. The historical study trim section is an annulus around a 15.805 mm bore and `cad/build_legacy_study.py` has always drawn it as one. 76.03 cm², not 129.61 |
| **P117** | **NEW, HIGH. The section's force needs a field above its own magnets' remanence** | `trim_stage.py` sets it from Gen5's lumped thrust constant, which A2 defines over `SLED_ACTIVE_LEN` = 0.34 m of flat array 0.09 m deep. A55 applied it to 0.14401 m of annulus, unrescaled for length or area. Over the real surface, 948.0 N at 90 kA/m needs **1.3854 T** against `motor_model.BR` = **1.32 T** |
| **P118** | **NEW, CRITICAL. The wall takes more force than the stator makes, and it does it for the whole stroke** | `drag / thrust = σdvB_net/2K` carries no area, no section length and no thrust constant, and it reaches one at **B_net = 0.1500 T**. Every field a permanent-magnet array produces is above it: 1.08 at 0.2 T, 3.24 at 0.6 T, 7.13 at the remanence. And the magnets ride the carriage, so they face the wall for all 8.0 m and not only the 144 mm under the stator. The magnet array's length is not in `cad/parameters.json`, so that integral cannot be closed yet |
| P92 | Answered, not closed, and it stays `COMPUTATION` | The comparison P92 named — the wall against the skin depth — is not the one that governs. The wall is 0.314 skin depths and removes a fifth of the field, because `Rm` = 0.7539 decides it and the tube never moves. Relabelling the entry `DECISION` would have taken one off the closure count for no work, which is the one failure that gate exists to catch |
| A66 | The wall temperature is reported without a gate, and the gap is stated rather than filled | I declared no band against the 473 K ceiling. The ceiling is crossed near 0.8 T, every campaign stack assumes the heat stays where it was made for four hours, and the axial diffusion length over ADR-020's 1200 s cadence is 287.8 mm — twice the section. The per-shot column is the part I would defend |
| Counts | Register 153 entries, 59 live. 71 run sheets, 68 analyses. historical study remaining COMPUTATION 17 → 19 | A66 is written, so it comes off the "numbered and never written" list in `README.md` |

---

## 2026-08-30 (sixtieth pass): the solver chain runs here again, and A4 reproduces

`tools/env-setup.sh` has named `calculix-ccx` and `ngspice` since it was written. Neither was in
this container, so the structural and circuit runs could be reproduced only on a GitHub runner.
For a repository whose argument is reproducibility that is the wrong way round, and it went
unnoticed because no gate re-runs them.

| ID | Item | Detail |
|---|---|---|
| Toolchain | CalculiX, ngspice, gfortran and qpdf installed, and each shown to work rather than merely to exist | ngspice reproduces the RC step at one time constant as 6.321204e-01 against an analytic 1 - 1/e = 0.632121. CalculiX solved both A4 decks |
| A4 | The structural run reproduces its published numbers on this machine | `validation/fea/build_deck.py` rebuilt both decks from `EMOCD_Sled_Gen3.step`, 3672 N over 340 x 90 mm, and CalculiX returned a peak airgap closure of 0.01945 mm pinned and 0.01600 mm clamped. The run sheet publishes 0.0194 and 0.0160. The bracket is reproduced, not asserted |
| Deps | `requirements-dev.txt` added, and the test harness moved into it | Nothing in that file produces a number that appears in the repository; it tests, cross-checks and lints the code that does. `requirements.txt` keeps the four packages the published numbers depend on. Versions are read from the environment rather than chosen, because a pin invented from memory is a made-up number like any other, and the first draft of this file had five of them wrong |
| Deps | Independent-check tooling, installed for a stated purpose | astropy, skyfield and sgp4 to cross-check the hand-rolled orbital model rather than replace it. mpmath and sympy to re-derive a suspect figure by another route. scikit-fem and meshio for a structural path independent of CalculiX. jsonschema for the results contract, so a renamed field fails a gate instead of a downstream read. pypdf and pdfplumber for the numbers inside a generated PDF. Pint is deliberately absent: the recent defects were same-unit semantic errors and a dimensional checker would not have caught one of them |
| CI | The workflow installs both requirement files | Otherwise the test gate added last pass would pass locally and be absent on the runner |

---

## 2026-08-30 (fifty-ninth pass): the verification that was thrown away every time is kept

Eighty-one analysis files, seventeen thousand lines, and exactly one of them carried a
self-test. There was no test runner and no `tests/`. Every fault injection this repository
has ever run -- nine against the document gate, nine against the freshness gate, four
against the P116 identities, three against the seed-path check -- was written in a
throwaway script, proved the fix on the day, and protected nothing afterwards. That is how
P114 and P116 came to be the same mistake twice.

| ID | Item | Detail |
|---|---|---|
| Tests | `tests/`, run by `verify_all.sh` and by CI | Thirty-one tests in three files, plus a README that says what they do not do. Not a replacement for a run sheet: bands in `validation/` are still the only place a claim is earned against a criterion declared before the script existed |
| Properties | Rules that must hold for ANY input, generated by hypothesis | The thirty-five identities in `host_reference.self_test()` check one altitude and one stage mass. P114 was a claim that is true at 500 km on a 1000 kg stage and false in general, and nothing evaluating only the reference point can tell those apart. Nine orbital properties and nine campaign properties now range over 200 to 2000 km and 400 to 3000 kg: a single impulse always out-raises the same dv spent as a complete transfer, a prograde impulse never moves perigee, the Hohmann inversion round-trips, burn duration scales exactly as one over thrust, every main-engine impulse reaches the floor and every impulse below it is assigned away, each leg starts where the last ended, a propagated campaign always reaches at least the naive multiple, and raising either the burn floor or the thrust never makes a case more executable |
| Regressions | Every shipped defect, reintroduced, with a gate required to catch it | P116 in both directions, the multiplied campaign duration, the campaign that never leaves its start orbit, the accounting that drops the auxiliary half, an edited value inside a generated block, a removed block marker, a one-ulp drift tolerated beside a factor-of-15.6 staleness caught, a flipped band verdict, a removed key, and the dead `$B` path in the issue seeder. Each asserts a failure list is NON-empty, so it fails when the defect stops being caught. A control test asserts the self-test passes when nothing is broken, without which the rest would pass against a self-test that always fails |
| Mutation | The suite is checked against the real source, not trusted | Halving the apogee rise, inverting the burn-floor comparison, disabling sequential propagation and perturbing burn duration by one per cent each turn it red, and it returns green when the source is restored. A test suite that has never been shown to fail is a claim, which is the same standard the document gate was held to |
| Identity count | Now recomputed independently in a test | It printed "25 identities hold" while the function held more. The count is read from the source at run time and a test recomputes it a second way and requires agreement |
| Deps | `pytest` and `hypothesis` are hard dependencies, not optional | `verify_all.sh` skips them with a stated reason rather than silently if they are absent, because a gate that disappears when a package is missing is worse than no gate |
| Gate | The companion gate accepted an export commit that no fresh clone would have | It asked `git cat-file -t`, which says the object exists in THIS clone. That stays true for a commit amended or rebased away: the object lingers locally and was never fetched anywhere else. The gate now also requires the recorded commit to be an ancestor of HEAD, which is the property that travels. It was found by causing it, amending a commit after running the exporter, and it is the same shape as the `59b3661` record that was failing on `origin/main` at the start of this session |

---

## 2026-08-30 (fifty-eighth pass): branch cleanup, and a dead link the gate was built not to see

Trimming the repository's branches turned up one real defect and one blind spot behind it.

| ID | Item | Detail |
|---|---|---|
| Link | `tools/seed_issues.sh` pointed at `docs/PHASE_II.md`, gone since VAULT-01 | That rename moved the file to `docs/VAULT.md` and retargeted twenty-one files. This one was missed, and the text is issue-seeding copy, so the dead link would have been published into a GitHub issue body where nobody re-runs a link checker. Repointed to `docs/VAULT.md`; PII-4 is still there and still the envelope-repackaging entry the issue means |
| Gate | `check_links.py` excluded the file it was in, so no gate could ever have caught it | The exclusion was written for relative link-shaped strings inside generators, which resolve in the file they are written into rather than in the generator's own directory. It swept up `seed_issues.sh` with them. But `$B` is the flagship base URL, so `$B/<path>` is an ABSOLUTE flagship path and does resolve against this checkout. Those paths are now checked, the comment says why they are different, and two injected faults confirm it fails on a renamed target and on a path that never existed. Four other `$B` targets in that file resolve |
| Branches | `ci-diagnostic` is cleared for deletion but could not be deleted from here | It sits at `ef1878f`, a strict ancestor of `main`, so it carries nothing to merge and removing it loses nothing. The deletion itself did not happen: this environment reaches GitHub through a proxy that terminates a push carrying no packfile, which is exactly what a delete refspec is, and four attempts failed identically. `git push origin --delete ci-diagnostic` from an ordinary clone will do it. The branch existed to prove that this repository's Actions settings refuse any workflow referencing a third-party action, which the fifty-fifth pass recorded and fixed |
| Branches | Two local-only refs dropped | `pre-public-sync-2026-08-22`, fully contained in `main`, and `pr16`, the pre-rewrite history rooted 2026-07-29 with no common ancestor with `main` at all. Four files existed only there and all four were checked before the ref was dropped: `docs/PHASE_II.md` is `docs/VAULT.md` now, `tools/export_portfolio_repos.py` is superseded by `tools/export_companion.py` which covers all three companions rather than the old three portfolio copies, and the two CAD briefs describe a Fusion 360 and AutoCAD workflow for a Fusion-authored Gen3-era model. The published Gen5 renders come from Blender on the STLs `build_gen5.py` writes, which is a different pipeline, and no 2D drawing set was ever produced from the AutoCAD brief. Nothing was carried across |

---

## 2026-08-27 (fifty-seventh pass): the mission cases could not be flown by the engine that was billed for them

A second independent review of the host-reference study, one day after the first. Three defects.
The first reverses the study's headline conclusion for the second time in two days, and it runs
opposite to the error P114 corrected: that one understated what the engine was asked to do, this
one credited the engine with manoeuvres it cannot perform.

| ID | Item | Detail |
|---|---|---|
| P116 | HIGH. Case B and Case C counted main-engine ignitions for impulses below the file's own minimum burn | Numbered under [ADR-021](docs/adr/021-freeze-the-register.md) rule 2. Section 10 computes that a 2 s burn on the 1000 kg reference stage at 20 kN is a 40.27 m/s command; section 11 then modelled 20 m/s and 40 m/s legs, whose individual impulses are 0.49 s and 0.94 s. Not one of the sixteen reaches the floor. The file published 7 and 11 post-primary ignitions, called the excess over the assumed budget of 4 its sharpest finding, and ranked restart count as the most valuable provider datum. All three followed from charging the engine for manoeuvres its declared envelope forbids. Every impulse is now checked and assigned to `MAIN_ENGINE` or `AUXILIARY_PROPULSION_REQUIRED`, three branches price what can actually be flown, and the hierarchy puts minimum impulse first and restart count second |
| Propagation | Sequential campaign altitude was a multiplication | Each leg was solved from 500 km and the first leg's raise multiplied by the leg count, published as "cumulative raise": 399 km over eleven legs. The same total dv buys more altitude from a higher orbit, so the campaign ends higher than the multiplication says. Propagated leg by leg, eleven legs reach 915.5 km, a net rise of 415.5 km, and the old figure was 3.9 % low. Mass propagates too, which is what makes the minimum commandable step grow along a campaign. Not numbered: an approximation error in an illustration, in the conservative direction, that reversed no conclusion |
| Pacing | Campaign duration was the first leg's arc times the leg count | The transfer ellipse grows with the orbit, so the arcs lengthen. Summed properly, Case C moves from 3.97 to 4.10 h and an eleven-leg campaign from 8.71 to 9.06 h. Not numbered, same reason |
| Branches | Three branches replace one infeasible reading | Branch 1, main engine only: the smallest shell change whose *each* impulse reaches the floor is 150.4 km and 81.9 m/s from 500 km, growing to 182.3 km by the fourth leg as the stage lightens, four steps inside the 120 kg customer allocation, ending at 1163.3 km. Branch 2, main engine plus auxiliary: every reposition impulse falls to auxiliary propulsion and the main engine performs only the 4.41 s disposal burn, leaving a demand of 60 m/s across six impulses for Case B and 200 m/s across ten for Case C, with no auxiliary capability assumed anywhere. Branch 3, hypothetical throttle: 24.5 % of baseline thrust for Case B and 46.8 % for Case C, marked a sensitivity and not a claim that any engine throttles |
| Architecture | The three-way split is now reached from both ends | Section 10 arrives at main engine coarse, auxiliary fine, VOLLEY for release from the fine end. Branch 2 arrives at the same split from the campaign end, independently. Two arguments landing on one architecture is worth more than either alone |
| Provider data | The engine rows are reordered by what actually decides the mission | Minimum stable burn, then minimum thrust and throttle envelope, then full-engine restart count, then vacuum thrust, then Isp, then restart dwell. The first two decide whether the main engine can command the required impulses at all; restart life matters after that. The earlier ranking put restart count first, which followed from the ignition count P116 corrects |
| Self-test | Ten identities added, guarding the corrections in both directions | An impulse marked executable must reach the floor and an impulse below the floor must be assigned away from the engine; leg *n* ends where leg *n+1* starts; net rise is the propagated difference and never below the naive multiple; duration is the sum of the arcs; main-engine and auxiliary counts equal what was assigned and add to twice the leg count; lowering the floor cannot reduce executability and a zero floor admits everything; raising thrust at a fixed floor cannot increase it; branch 1's binding impulse reaches the floor exactly |
| Self-test | The identity count was hardcoded and had gone stale | It printed "25 identities hold" while the function held more. It is now counted from the source at run time, which is the same staleness the results-freshness gate exists to catch, one level up |
| P114 | Superseded in part, not rewritten | Its ignition arithmetic stands: a shell change is two impulses and disposal is a third ignition. The conclusion drawn from it does not, and the entry now says so and points at P116. Retained as the published record |
| P113 | More important, not closed | Stays `PROGRAMME`, `COMPUTATION`, `LIVE`. If a host main engine cannot perform fine shell changes, dividing orbital work between host, auxiliary propulsion and deployer is a harder problem than the file made it look, not an easier one |
| P108 | Untouched | The historical study design point stays at 29.009 m/s. Nothing in this pass lowers a VOLLEY requirement, and the assumed 4-ignition budget stays a `VOLLEY_ASSUMPTION` wherever it appears rather than becoming an engine figure |
| Sources | Two retrievals re-attempted, both still blocked | The specific turbopump article and a company-owned ignition post were re-attempted on 2026-08-27. Both return a 403 at this network's own proxy, before the publisher is reached. No row is promoted to `COMPANY_PRIMARY`, every claim keeps its `SEARCH_SUMMARY` mark, and the file now says that S2 is cited by article title against a landing-page URL because the article-level URL could not be confirmed from here |
| CI | The drift step still demanded byte identity of floating-point output | It regenerated `host_reference.json` and ran `git diff --exit-code`, and on a GitHub runner the transfer-arc sums came back one ulp apart: 143.62078713217508 against 143.6207871321751. `pow` and division are not required to be correctly rounded, so that disagreement is irreducible and is the same class as P115. The file was already being regenerated and compared numerically by the freshness gate one step earlier, with a declared tolerance and a reason, so the byte comparison was a second and incompatible standard applied to the same file. It is removed from the drift step in both the workflow and `verify_all.sh`, with the reason written beside it. The generators that remain there emit integers and formatted text, where byte identity is achievable |

---

## 2026-08-26 (fifty-sixth pass): the penalty supports in A69, and a wrong diagnosis withdrawn

The fifty-fifth pass ended by setting a per-file reproducibility tolerance on two results files
and explaining the wider of the two as cancellation in a sagitta. That explanation was wrong.
Running the gate a second time on a runner, with the disagreement reported field by field,
named A69's own fields rather than A70's, and at 8.5e-4 rather than 1.3e-4.

| ID | Item | Detail |
|---|---|---|
| P115 | MEDIUM. `tube_centreline.beam()` held its rigid supports with a 1e8 diagonal penalty, at cond 8.6e15 | Numbered under [ADR-021](docs/adr/021-freeze-the-register.md) rule 2. The penalty satisfies the constraint to 1e-17 m and destroys the interior of the solution: against a double-precision epsilon of 2.2e-16 there is nothing left along the worst direction. Only the cases with a prescribed support OFFSET moved, because only those put the penalty into the right-hand side as well as the diagonal, which is exactly the set of fields the runner named. The supports are now imposed by eliminating the constrained rows, cond 4.1e9. A69's support-placement peak goes 0.0768 to 0.0769 mm; every band verdict in A69 and A70 is unchanged and A70's printed sagitta map does not move at all |
| Diagnosis | The cancellation explanation is withdrawn | It attributed the cross-machine disagreement to A69 reproducing at 3e-9 and a three-point sagitta amplifying that by about 33,000. The amplification is a real property of a sagitta; it was not what happened. A70's sagittas moved by 5e-5 against an input that moved by 8.5e-4, which is less than their input rather than 33,000 times more, and the local 3e-9 was a same-machine re-run that could not see conditioning at all |
| Tolerance | 1e-3 on `guided_contact_derived.json` is withdrawn with it | It was set on the withdrawn reasoning and it would have passed the gate with the defect still in place. Both files now carry 1e-7, measured by perturbing every entry of the matrix and the right-hand side by one ulp and re-solving: the penalty formulation spreads by 4.3e-3 and the eliminated one by 4.4e-8. The observed 8.5e-4 sits inside the first and five orders outside the second |
| A69 | `free_free_first_mode()` picked the rigid-body modes by sign | A free-free beam's two rigid modes are zero; discretisation puts them at 1.1e-4 and 4.5e-4 against 110.5 for the first elastic mode. Keeping the eigenvalues above zero and dropping the first two means a numerically-zero eigenvalue landing a hair below zero on some other LAPACK is discarded, the slice moves by one, and the function returns the SECOND elastic mode at 2.76x. Under a one-ulp perturbation the sign filter moved by 1.76 relative and selection by magnitude by 2.0e-6. Not numbered: this machine and the runner both picked the right mode and 1.6729 Hz is unchanged, so nothing published was wrong |
| Gate | Three leaves carry their own tolerance instead of loosening a file | The free-free mode at 1e-5 relative, and the two `err_pct` residuals at 1e-5 absolute. Those two are 3.4e-7 and 2.3e-6 PERCENT -- differences of numbers agreeing to fifteen digits, with no significant figures to reproduce -- and band 1 tests them at 0.5 %. Nine faults were injected to check the arrangement, including one that substitutes the second elastic mode for the first |
| Gate | The freshness gate left its own output in the working tree | It re-runs a script, compares, and on a pass left the regenerated file in place. On one machine that is byte-identical and invisible; on a runner it is a real difference, and CI's next step -- `git diff --exit-code` after regenerating the generated documents -- failed on a file this gate had written rather than on anything that had drifted. It now restores the committed file after every comparison, pass or fail. A checker that leaves its output behind is a generator |
| Gate | The document gate's coverage is now stated in the document | The markers hold the tables and the tables are 12 per cent of the file. Three further faults were injected at the edge -- a figure, a unit and a verdict word altered inside a sentence rather than a block -- and the gate passes all three. That is the surface P114 lived on: a correct total in a table with a sentence beside it reading that total as one burn. The file now says so instead of leaving the reader to infer the gate covers more than it does |

---

## 2026-08-26 (fifty-fifth pass): the host-reference study is audited, and its orbital model was wrong

An independent review of `docs/HOST_REFERENCE_CASES.md`, on the day it was published, found six
defects. One is numbered under [ADR-021](docs/adr/021-freeze-the-register.md) rule 2 as a model
error that made a published document wrong. The other five are claim withdrawals, a missing
sweep, a weak gate and an infrastructure fault, none of which that ADR permits into the register.

| ID | Item | Detail |
|---|---|---|
| P114 | HIGH. The model conflated a manoeuvre with the impulses that perform it, in two places | Numbered. It published a total two-impulse Hohmann budget as an "equivalent altitude step" and read it in prose as one burn, and it counted repositioning legs as ignitions. Corrected by vis-viva, a bisected Hohmann inverse, and an explicit ignition schema. The second surface reverses a published conclusion: Case B needs 7 post-primary ignitions against an assumed budget of 4, not 3 |
| Pacing | The one-orbit-per-leg case was called "the real pace" | Withdrawn. One orbital period per leg is an illustrative scheduling case, not a lower bound: a Hohmann transfer reaches the opposite apsis in about half an orbit. Three pacing cases are now shown, the 47 minute transfer arc is separated out as the only physical duration, and the conclusion that "time is the binding constraint" is replaced by a statement conditioned on the scenario |
| Batching | A fixed-dv-per-reposition table was presented as evidence that batching wins | Withdrawn. The rows do not deliver the same mission, which the code's own docstring conceded while the prose drew the conclusion anyway. Renamed reposition-count scaling, bounded to what it shows, and a fair equal-mission batching trade is left explicitly open under P113 |
| Thrust | A 15 to 30 kN sensitivity was declared in the ledger and never swept | Swept. At 15, 20 and 30 kN the 2 s floor on the reference stage is 30.2, 40.3 and 60.6 m/s, so the coarse-actuator conclusion survives the whole declared range. The ledger gains a "Swept?" column, so an unswept sensitivity is now visible rather than implicit |
| Gate | `--check-doc` checked presence, not agreement | It asked whether each formatted number appeared anywhere in the document, so a correct value beside a wrong label passed. Sixteen tables are now generated between markers and compared as exact text. Nine faults were injected to demonstrate it fails on each, including the two the old gate could not see |
| CI | The `gates` workflow had never once run | Every run since 2026-08-22 ended in `startup_failure` with zero jobs. The cause is not the file: this repository's Actions settings do not permit third-party actions, so any workflow referencing `actions/checkout` is refused before dispatch. Demonstrated by running five workflows on one branch, four with `actions/checkout@v4` and one with no action at all; only the last started. `gates.yml` now fetches with git and uses the runner's own Python, and the reason is written into the file so nobody reinstates a `uses:` line |
| Sources | The evidence table cited "company material" rather than documents | Eight sources now carry title and URL, the taxonomy separates company-issued text relayed by a wire from trade reporting, and every row records how it was retrieved. No row is COMPANY_PRIMARY: the hosts return a policy denial to the network this study runs on, so nothing was read on the company's own property, and the table says so |
| Evidence | "Semi-cryogenic" was used to establish the propellant pair | It cannot. Semi-cryogenic is an architecture family. The propellant row is now owned by the turbopump design publication, which names LOX and kerosene, and the semi-cryogenic row is context only |
| Heading | The section title and diagram implied established engine restart | Retitled to name the stage as assumed, and the diagram step reads MAIN-ENGINE RESTART, ASSUMED. Whole-engine restart is not publicly established for this case and the file must not be quotable as saying it is |
| README | The front page said the host repositions "on its own reaction control" | Too specific, and it contradicted the Class A/B/C architecture. A host may use main propulsion, auxiliary propulsion, reaction control, some combination, or none. Now reads "whatever planned post-primary propulsion authority the host makes available" |
| Freshness | The results-freshness gate compared floating-point JSON byte-for-byte, which no two machines can satisfy | Found the moment CI first ran: `run_a69.py` and `run_a70.py` reproduce byte-identically here and not on a GitHub runner, because both solve eigenvalue and linear systems through numpy and the last bits depend on the BLAS the interpreter was built against. The gate had only ever executed on one machine, so an unachievable claim had gone unnoticed. Values are now compared at 1e-9 relative with everything non-numeric still compared exactly. Not a weakening: P110's staleness was a factor of 15.6, and the new comparison was shown to catch a 2-parts-in-1e9 drift, a flipped band verdict, a 1 % list element, a changed string and a removed key, while tolerating one part in 1e16 |
| A70 | The admissibility sagittas carry about 1e-4 of numerical noise, by construction | Measured when the first tolerance was still too tight to pass on a runner. A69's centreline reproduces to 3e-9, ordinary BLAS sensitivity in a linear solve. A70's sagittas reproduce only to 1.3e-4, and the reason is cancellation: a three-point sagitta subtracts nearly equal ordinates, about 1.627 mm at the 40 mm land, to leave 0.049 um, amplifying relative error by roughly 33,000. 3e-9 times that is 1e-4, which is what is observed. The figure is conditioned badly by construction rather than computed badly, and nothing physical moves: 0.43398 um against 0.43404 um on a 25 um radial clearance, where A70's conclusions are factors of two. Tolerances are now per file with the reason beside each, and the gate still catches staleness by three orders of magnitude. Embedded numbers inside run-sheet detail strings are compared numerically too, so a moved value is tolerated while a changed verdict word is not |
| P113 | Re-audited, scope confirmed | Stays `PROGRAMME` and `COMPUTATION`. The corrected model widened what closing it requires, because it shows ignition count, shell choice and release velocity to be coupled. It is not moved to `historical study`, not closed by this study, and not used to lower any historical study requirement |

---

## 2026-08-20 (fifty-third pass): the visuals reach the front pages, and A35 turns out to be stale

| ID | Item | Detail |
|---|---|---|
| P95 | CRITICAL. A35's headline figure is pre-A46, and correcting it reverses A35's own escape route | Found while drawing the ledger for the front page: the figure would not agree with the text, and the figure was right. `constraint_ledger.json` was regenerated on 2026-08-16 in the *"Apply A46"* commit; the run sheet was last touched on the 14th. 49.23 kg / 58.2 % to 88.67 kg / 70.06 %, and per satellite 4.10 to 7.39 kg. *A35's one route out of kill criterion 1, "at twenty-four satellites the same 49.23 kg is 2.05 kg each, and the criterion closes", is 3.69 kg each and does not close.* Propagated to seven documents; A35 annotated with a dated block, no band re-declared. |
| A2/A3 | The field map, drawn for the first time | `analysis/make_field_map.py`, from `field_3d.halbach_pair()`, extracted from `kt_depth_resolved` so the picture and the thrust integral build the same geometry. Kt verified unchanged at 10.5386. Centre-plane 0.5041 T against a depth mean of 0.4759 T, the assumption A2 corrected. |
| A35 | The ledger, drawn | `analysis/make_ledger_figure.py`. Three of the six requirements carry no mass on their own; no corner of the 64 reaches the criterion. |
| Blender | An exploded view, and the renderer learned to do them | `build_scene()` now accepts `(name, (dx,dy,dz))` as well as a bare name, so every view written before exploded views existed behaves identically. Two framings were discarded before one read as a stack rather than scattered parts. |
| Front pages | Four pages had no images at all | `VOLLEY-lab` contained no image file of any kind; the paper and thesis each had 17 figures in their own directory and referenced none. All four now lead with something, by `raw.githubusercontent.com` URL where the repo holds no binaries, one copy of each render in the programme. Every raw URL verified against a file already pushed. |
| VOLLEY | README Results and the Pages site | Both gain the flow field, the field map, the exploded stack and the ledger. Captions carry the caveats: the CFD pressure term is solved, the viscous term is bounded and not. |

---

## 2026-08-20 (fifty-second pass): a provenance audit of every constant

| ID | Item | Detail |
|---|---|---|
| P94 | A13 band 5 passes on a host control authority E5 says does not exist | `RCS_TORQUE = 0.1` sat in `attitude_budget.py` with no units, no comment and no source, and A13 band 5 passes on it: *"settling below 0.01 °/s with a 0.1 N·m RCS authority."* `EXTERNAL_EVIDENCE.md` records E5 as "no host propellant or control authority figure exists." *The project recorded that it had no such figure and used one to pass a band.* Labelled a declared assumption in script and run sheet, cross-linked to E5, verdict annotated rather than re-declared. No source was invented. |
| A13 | The deployer inertia was 40 % low, and correcting it improved the result | `M_DEPLOYER` was the literal 124.5 kg, `mass_properties`' loaded figure *before* A46. `deployer_inertia()` is added to the host's, so the rotating body is the loaded deployer: 174.6 kg, now read live from the results file. At 500 kg host: inertia 329.7 to 345.0 kg·m², return peak 0.13625 to 0.13021 °/s, offset 0.42074 to 0.40209 °. At 200 kg the return peak falls 0.44323 to 0.38512. Rows 3 and 4 still FAIL, *a correction that improves numbers is reported like one that damages them.* Propagated to both manuscripts and both PDFs rebuilt. |
| P93 | A fifth instance, inside the script that computes the right answer | `mass_properties.py`'s docstring still read 76.5 / 124.5 / 0.44. Its own JSON says 126.6 / 174.6 / 0.46. Six lines below sits the line *"A docstring is the first thing anyone reads about a script, so it is worth as much as the code under it."* Corrected, with the A46 history recorded in the style the docstring already used. |
| Audit | 126 scalar constants scanned; 14 labelled | Every module-level scalar in all 68 analysis scripts, excluding universal constants and sweep ranges. The declaration discipline held: A46's seven assumed enclosure inputs, driving the 50.04 kg that is 58.6 % of the stage credit, are all declared, and its band 7 says *"zero undeclared."* `RCS_TORQUE` was the only genuine contradiction in 126. `BEARING_KG`, `CONVERTER_KG_PER_KW`, `Q_DESIGN`, `MOS_TARGET`, `M_DIST`, `ECC`, `M_STOWED`, `SIGMA`, `TAU`, `MAG_FULL_SCALE`, `SEAL_CP` and `ASSUMED_ARM` now name themselves as declared assumptions beside the code. The remaining 112 are design choices and named cross-run imports, not unsourced claims. |
| Satellites | Clean | `pulsed-linear-motor-design-lab`, `orbital-deployment-trade-study` and `engineering-evidence-toolkit` carry no superseded VOLLEY figures outside their `reference/` copies. The only hits are unit-test fixtures passing `16.388` as a function argument, inputs under test, not claims. |
| Scope | This audited code, not prose | A full trace of every asserted number in `docs/` back to a results file is a larger job. P93 is the proof it is needed, and `tools/check_paper.py` is the right shape for it. |

---

## 2026-08-20 (fifty-first pass): Gen5 closes

| ID | Item | Detail |
|---|---|---|
| P93 | CLOSED, and the entry was wrong about its own cost | It called for a re-run. `payload_family.py` already read `dry_kg` live and `payload_family.json` already carried 126.6 with all nine rows. *The analysis was current the whole time; only the manuscript was stale.* |
| P93 | Fixing it exposed two things the audit had missed | A third stale mass in the mechanical section (84.5 / 132.5 / CoG 0.44 m to 126.6 / 174.6 / 0.46), and the family table stale in every column, its velocities were at the pre-ADR-030 point, so the 3U row read 16.4 m/s at 10.5 g against the paper's own rated 16.0 at 10.1 two paragraphs earlier. The table contradicted its own paper, and seven rows were 76.5-based while the 3U row alone was 84.5-based. |
| Family table | Regenerated from `payload_family.json` | All eight rows, all five columns. 3U is 10.550 kg/satellite. The *"factor of thirty across the family"* claim, invariant in dry mass, therefore always checkable, is 109x. |
| A29 | The flow field, at last | `validation/cfd/fields.py` parses the committed case in pure Python, `postProcess` aborts in this OpenFOAM 1912 build with an IOstream error, the same class of failure A29 recorded for `wallShearStress`. 721 781 points, 1 884 060 faces, 581 779 cells. The mid-plane slice shows stagnation at the nose, separation at the shoulders and a wake unrecovered by x = 2.2 m, A29's "classic bluff-body split", visible for the first time. |
| Figures | `A29_cfd_report.png` was an orphan in both manuscripts | Present in `figures/` since it was generated and referenced by neither `paper.tex`. The paper had never once shown its CFD work. Rescued, and the new wake figure placed beside it. Unreferenced-figure count in both repos is now zero. |
| Captions | Both CFD captions state the bound | The pressure term is integrated from the solved field; the viscous term is not solved and is bounded by a flat-plate correlation. *A picture of a result must not imply more than the result claims.* |

---

## 2026-08-20 (fiftieth pass): Gen5 closes, and the paper does not

| ID | Item | Detail |
|---|---|---|
| P93 | CRITICAL. The paper's system mass is 50 % low, in its own abstract | `mass_properties.py` and `BASELINE.md` give 126.6 kg dry; `paper.tex` says 84.5 kg in the abstract and conclusion and 76.5 kg in the payload-family table caption. The arithmetic names the cause: A46 itemised the enclosure on 2026-08-16, an 8.00 kg placeholder becoming 50.04 kg, and 84.5 − 8.00 + 50.04 = 126.54; 84.5 − 8.00 = 76.5 is the caption. Both figures are pre-A46 and the paper was built three days after it landed. It is a re-run, not a patch, the caption states per-satellite mass *uses* 76.5 kg, so every row of that table moves by 65 %. Nothing compares the paper against `BASELINE.md`: P84's shape, one deliverable further out. |
| A7 | Superseded, and the closure document said otherwise | A7 was specified and correctly never run, Chrono unavailable, and the release mechanism it would simulate is undefined. A7-R gave the budget (1.465 mN·m·s), A23 modelled three rigid-body stages with mechanism properties as swept axes (ideal release 0 °/s, skew tolerance 50.6 µs, cradle reaction 85.0 N against 200 N), A34 closed the impact five of five (settles in 27.25 ms of a 146.4 ms stroke, exactly zero residual rate). `PHASE_I_CLOSURE.md` listed A7 as unrun Category A work until today, ten days after A23 answered it, *a stale gap inside the closure document itself.* |
| GEN5_CLOSURE | New: `docs/GEN5_CLOSURE.md` | The whole Phase I case on one page, what Gen5 is, every headline number against its source, what was cross-checked and by what tool, what failed, the seven kill criteria with three crossed and unmoved, the permanent caveats (E4, A9 re-tested at 403 today, T-1...T-8, B-1...B-4), and the handoff to hardware. It states that all four specified benchtop tests validate subsystems ADR-032 deleted, so the benchtop programme is Gen5's closure rather than historical study's start. |
| P16 | README's description was stale, not the paper | `paper.tex` withdrew the invariance claim in the abstract, §V-B, the sensitivity and limitations sections, and the built PDF carries it. The README said the opposite. *The source was fixed and the summary was not.* What remains open is the replacement claim, which needs A9, still 403 at CONNECT, re-tested. |
| Paper / thesis | historical study added as future work; both PDFs rebuilt from source | A bounded section: the architecture change, what it deletes, that nothing in it is measured, that its trim stage is suspended, and that it is reported in the repository rather than the paper *for the same reason the 3-D field correction is computed and deliberately not applied.* Both PDFs now demonstrably rebuild, the check that would have caught the stale P16 description. |
| CFD | Flow-field visualisation not produced, and why | The converged fine free-stream case is committed and reconstructed at t = 1800. `postProcess` aborts in this OpenFOAM 1912 build with an IOstream error, the same class of failure A29 already documented for `wallShearStress`. Not forced, and recorded rather than worked around. |

---

## 2026-08-20 (forty-ninth pass): the stage credit at the store that was actually sized

| ID | Item | Detail |
|---|---|---|
| A45-R2 | The stage credit re-run at A56's store, four of eight, all five predictions held | A45 and A45-R both read the store as A43's 5.38 kg. A56 sized it at ADR-034's charge pressure and got 3.1216, 42 % lighter, and nothing depending on it had been re-run. The allowance moves for the first time: A45-R's finding was *"the allowance never moved, the credit did"*, and sizing the store takes it 7.17 to 9.43 kg, break-even 8.4 % to 11.0 %. |
| P68 | Still CRITICAL | Full credit 1.4027 to 1.2145 kg/satellite, hostile 3.2709 to 3.0827. ADR-032's falsifier fires by a third less and still fires, at 11.0 % against a declared 30 %. *A CRITICAL entry improving is not a CRITICAL entry resolved.* The 16.5 % the entry quotes is against the 43.33 kg credit A46 replaced, a break-even percentage means nothing without the credit it is a fraction of. |
| MASS-01 | The project was publishing three figures for one quantity | 1.403 (A45/A45-R/P68, at 5.38 kg), 1.296 (README, index.html, GENERATIONS, at ADR-034's scaled 4.10 kg) and 1.324 (historical study.md, same store *plus* the trim stage). None was wrong for its own scope and no page said which scope it was using, the front page's hostile 3.164 is the 4.10 row while P68's 3.108 is A45's at 5.38. A45-R2 band 8 reconciles all five readings and names 1.2145 kg/satellite canonical: A56's sized store, without the trim stage, because ADR-036 suspended it. Any page quoting 1.3173 must say it includes a section that may not be built. |
| A45 / A45-R | Frozen against drift | `stage_credit.py` gains `STORE_KG_A43 = 5.38` and reads the live store from `cad/parameters.json`; `main()` raises if the A43 helper stops reproducing. Band 1 re-evaluates the whole model at the frozen store and must return 85.36 / 1.403 / 3.271. *A44 and A48 drifted silently because nothing did this.* |
| Propagation | Six documents | `README.md` (twice), `docs/index.html`, `docs/GENERATIONS.md`, `docs/generations/LEGACY_STUDY.md`, `docs/KILL_CRITERIA.md`, `docs/LEGACY_STUDY_CLOSURE.md`, and a dated block on ADR-032's falsifier 1. ADR-034's own table keeps 1.296, it is that decision's record of what it decided. |

---

## 2026-08-20 (forty-eighth pass): the seal is specified, and the trim stage stops

| ID | Item | Detail |
|---|---|---|
| ADR-036 | The seal is specified at 17.8 N and the trim stage is suspended | No new analysis. [A61](validation/A61_seal_class.md) band 3 had already run it: a seal meeting its own thermal requirement, 4.00 %, set by A58 band 5, is tighter than the 5.00 % at which the trim stage stops earning its mass, so one strictly implies the other. The stage is not deleted: deleting on a specification would repeat ADR-033's own error of adopting before the falsifier was answered. Work stops until P67. |
| P89 | Closed | `cad/parameters.json` gains a `LEGACY_STUDY_seal` group carrying both numbers and saying which is which, `friction_max_N` 17.8 as the specification, `friction_allowance_N` 83.40371375447981 as A41's retained ceiling, 4.68x apart, plus `measured: NO`. |
| P84 | Two dated scripts frozen at their own design points | `LEGACY_STUDY_dispersion.py` gains `STROKE_A44 = 2.18` and `trim_stage.py` `STROKE_A48 = 2.18`, the pattern `precharged.py` already used for `STROKE_A41` and that had not been applied here. A44 was computing a shot at 50 bar over 8.0 m, a point never adopted, and returning 1.504 % against its published 1.113 %. A48 band 3 was reporting 0.497 % where A48 declared 1.822 %. Both reproduce exactly again. |
| P84 | Its own closing sentence corrected | It claimed historical study's dispersion at ADR-034's point *"is not known"*. It was known: A55 computed 3.9798 % on 2026-08-19 and A61 reproduced it. *The defect was never a missing number, it was that the number never propagated.* |
| DISP-01 | 3.9798 % propagated into four documents | `ADR-033`, `docs/GENERATIONS.md`, `docs/BUILD_READINESS.md` and `docs/generations/LEGACY_STUDY.md` all carried A44's 1.113 % as historical study's figure, 3.6x low. Every surviving instance is now explicitly attributed to A44's 2.18 m machine. Friction's variance share rises with it, 93.4 % to 98.68 %. |
| P92 | Deferred, not dropped | A66 is not written: computing how well a stator couples through a conducting tube is only worth doing for a stator that will exist. Stays LIVE. If P67 measures above 22.3 N, it becomes the next run with nothing in front of it. |
| P67 | Now decides an architecture | It has a threshold in the unit seal data is quoted in: <= 17.8 N closes P88 and retires the stage; > 22.3 N fires ADR-036 falsifier 1 and ADR-033 stands. |
| CAD-07 | `unit_for()` asserted "mm" for every physical quantity historical study added | Not numbered, a `tools/` defect under ADR-021. `cad/DIMENSIONS.md` rendered 200 bar as "200.0 mm", a 473 K ceiling as "473.0 mm", a 3.1216 kg store as "3.1216 mm", and `first_fill_s` as dimensionless because "fill" appears in the name. The suffix table now covers kg, bar, K, J, W, A, Hz, L, s, m/s, m², m³, kg/m³ and N/kA·m, with a containment pass for qualified names like `exit_velocity_m_s_zero_friction`. Geometry keys are unchanged. *This is the document whose stated purpose is to be read instead of the JSON by whoever is cutting metal.* |

---

## 2026-08-19 (forty-sixth pass): the stroke becomes the stage

| ID | Item | Detail |
|---|---|---|
| A49 | The velocity, acceleration and stroke surface, seven of nine bands | 14 of 63 points beat the adopted historical study on exit velocity, peak acceleration and gas per shot at once. All fourteen sit at L = 8.0 m, A37's whole usable acceleration length. Band 3 confirmed peak acceleration is independent of stroke, `a_peak = p₀A/m` contains no *L*, so stroke is an exchange rate between charge pressure and velocity, not a performance knob. |
| ADR-034 | Adopted: 8.0 m of stroke at 22.73 bar | Exit velocity held at 29.009 m/s (34.280 zero-friction), peak acceleration 25.00 to 11.36 g, gas per shot 112.3 to 51.0 g. Both falls are 54.55 %, from the same charge-pressure change. Added mass per satellite 1.403 to 1.296 kg. |
| P78 | A49 band 6 failed, and it is the finding rather than the failure | Friction scales linearly with contact length while shot work saturates, so friction's share rises across the sweep: 9.75 % to 12.90 % at fixed pressure, and 28.39 % at the adopted point. The gap between the two velocity numerators widens from 5.00 % to 15.38 %. P67 now governs the design point rather than a correction to it. |
| VEL-01 | The velocity increase was available and was not taken | The Pareto front carries 30.97 m/s at 12.5 g, dominating on all three axes and 6.8 % faster. Taking it would invalidate A15, A20, A44, A50 and A52 at once, none of which has been re-run. A number moves when its consequences have been run. The follow-on is named in ADR-034. |
| P82 | The reservoir is still sized for 50 bar refills | 9.55 L at 200 bar, from A43's thermal argument at the old charge pressure. The ~ 4.10 kg store ADR-034 quotes is A49's gas-ratio scaling, not a sized store, and the reservoir saving is the whole of the mass argument, the tube itself gains 0.829 kg. |
| P83 | The trim stage's authority was sized at a friction share that has tripled | A48 sized ±0.323 m/s against A44's dispersion at 9.75 % friction; the adopted point runs at 28.39 %. Neither A44 nor A48 has been re-run. HIGH, because a larger authority makes ADR-033's unweighed pulse store, the project's most likely falsifier, more likely. |
| P81 | And the backup ejector got 3.67x worse | Clearing the sealed tube cost 181.8 J at 2.18 m against a 4.5 J ejector. At 8.0 m it is 667.2 J, a 148x shortfall. A53's masses are the 2.18 m case and are no longer governing. |
| CAD-G6R | historical study regenerated and re-rendered at the new geometry | Drive tube, stage rail and trim stator rebuilt; six geometry checks read back against `parameters.json` and pass. The renders were reframed, the assembly is 8.2 m at roughly 42:1, and the old camera distances put it off both edges. |
| CHECK-04 | A magic number in the geometry check, found by moving the design point | `build_legacy_study.py` compared the constant-pressure velocity bound against a bare 32.7, correct at 2.18 m and 50 bar and silently wrong anywhere else. It now reads the parameter it is derived from. |
| INDEX-01 | The run-sheet index was eleven runs out of date | `validation/README.md` stopped at A42. A43 through A53 are now indexed with their verdicts. |
| CLOSURE-01 | `docs/LEGACY_STUDY_CLOSURE.md` rewritten against what actually ran | Its Category A listed a provisional A49, A55 made before the design surface existed. Five of those runs happened under different numbers and one was not on the list at all. Remaining work renumbered A54, A60, with the structural case for an 8 m tube at 1 mm wall promoted to fourth. |

What authorised it. A49's bands were declared before `analysis/design_surface.py` existed.
No band was edited after a run, the two that failed are recorded as a declaration error and as
P78, and the design point moved rather than the band. All four checks pass.

> This file skipped five days, and the gap is stated rather than backfilled. The pass below is
> dated 2026-08-14. A43 through A48, ADR-033 and A50 through A53 all happened between then and
> this entry and were never logged here. Each is recorded in its own run sheet, in
> `OPEN_PROBLEMS.md` and in `validation/README.md`; this log is the thing that fell behind, and
> writing the missing passes now, from memory of what the other files already say, would be a
> reconstruction rather than a record. It is left as a gap.

---

## 2026-08-14 (forty-fifth pass): historical study exists as geometry

| ID | Item | Detail |
|---|---|---|
| CAD-G6 | `cad/build_legacy_study.py`, generated from the same `parameters.json` | Six parts, byte-stable across rebuilds, and every dimension is a run result rather than a choice: bore and stroke from A39, chamber from A41, reservoir from A42, cradle preload from A38. Six geometry checks read back against the parameter file and pass. |
| PARAM-01 | `LEGACY_STUDY_drive` and `LEGACY_STUDY_store` added to the parameter file | The single source of truth now carries both generations. Gen5 regenerates byte-identically against the extended file, which is what a generated model is for. |
| INHERIT-01 | One part of six is inherited, and it is the right one | The magazine cassette. A36 and A37 agree from opposite directions that the containment is the only subsystem surviving every architecture deletion, 11.45 kg of it. |
| HONEST-03 | Three things it draws that are not settled, in the script's own header | The reservoir carries 11.25 L, the adiabatic end of P64, when the isothermal figure at this cadence is 7.65. The cradle is an envelope, not a design, A34 says the mechanism does not exist and A38 raised its preload to 201.7 N against a <= 1 N release residual. And the stage rail is a straight extrusion of unknown provenance, because no provider has agreed to anything and A37's 43.33 kg stage credit is the least-examined number in the architecture. |
| GUARD-01 | `check_artifacts.py` guards historical study against its sources | One STEP guards the set: they are written in a single pass or not at all, the same rule Gen5 uses. |
| CHECK-01 | And the guard produced a false positive on Gen5, which is a defect in the guard | Adding `LEGACY_STUDY_drive` and `LEGACY_STUDY_store` to `parameters.json` made Gen5's STEP *older than its source* by commit time, while it regenerates byte-identically. Commit time is a lossy proxy for currency: a source can change in a way an artifact does not depend on. |
| CHECK-02 | Fixed by proving currency rather than inferring it | A pair may now name a regenerator. One that looks stale by time is rebuilt and compared; if nothing changes it was current and the timestamp was lying. Pairs with no regenerator keep the time comparison. |
| CHECK-03 | It also caught a true positive on the same run | `cad/BUILD.json` really was stale, its recorded `parameters.json` hash, and `DIMENSIONS.md` missing both new groups. The check was right once and wrong once, in the same pass, which is the argument for the fix rather than against the check. |

What authorised it. A41 and A42 fixing the last free dimensions. No band was edited, no
analysis was re-run to suit the geometry, and the geometry check reads the parameter file rather
than restating it. All four checks pass.

---

## 2026-08-14 (forty-fourth pass): filling is not the constraint, and the bottle cannot give its gas back

| ID | Item | Detail |
|---|---|---|
| A42 | Five of six bands. ADR-032's replacement falsifier is answered | *Can a 2 L chamber be filled to 50 bar inside the inter-shot window?* Yes, 4.14 s through a 1 mm orifice, against the 4 s index plus 6 s return already in the cadence. Filling is not the constraint. |
| P64 | A41's reservoir is sized on gas the bottle cannot give back | A41 divided total charge by storage pressure, which assumes the bottle can be drawn to zero. Below the charge pressure it cannot fill a 50 bar chamber. A42 measures it running out at shot seven of twelve. |
| BOUND-01 | The correction is bounded, not single-valued, and the reason is A42's own model | It treats the reservoir as adiabatic, so it cools as it empties, right for a fast blowdown, wrong for a twenty-minute cadence where the bottle re-equilibrates. Isothermal 7.65 L / 4.67 kg; adiabatic 11.25 L / 6.01 kg. Band 3 fails at either end and bands 5 and 6 pass at either end, so the architecture is not in doubt, the store mass is, by about 1.3 kg. |
| MASS-03 | Added mass per satellite, corrected | 1.344 to 1.455 kg against an unmoved 2.0 kg threshold, from A41's optimistic 1.343. Dry mass per satellite still crosses at 7.042 and both are still reported together. |
| PRED-03 | The first prediction this session that held | Declared before the run: *band 3 fails, everything else passes, fill is roughly 4 s at 1 mm, the correction is 6 L to 8 L.* Fill was 4.14 s, band 3 failed alone, and the isothermal correction is 7.65 L. It is also the first that was checked with a calculation before being written down, three of the four wrong ones were intuitions. |
| REPAIR-02 | And the cheap repair is already visible | The fired chamber vents 43 bar of a 2 L volume every shot and nothing models recovering it. That is where the reservoir shrinks if it ever needs to. |

What authorised it. ADR-032's own replacement falsifier, and a second question found while
scoping it. No band was edited, widened or moved; A42's six were committed before
`analysis/fill_window.py` existed, and band 3 was deliberately declared at A41's 6 L rather than
at the 8 L the scoping arithmetic gave, because a band restated to match a number already
computed tests nothing. All four checks pass.

---

## 2026-08-14 (forty-third pass): the store is specified, and three predictions in a row were wrong

| ID | Item | Detail |
|---|---|---|
| A41 | Eight of eight bands. historical study's energy store is specified | A 2 litre chamber at 50 bar, charged over the sixty seconds already spent indexing and fired as a closed adiabatic expansion. 30.54 m/s at 25 g on a 4.66 kg store. |
| P63 | Closed by deleting the component rather than pricing it | A40 showed the fixed orifice fails and A39's 2.98 kg assumed an unnamed regulator. There is no regulator. A pre-charged chamber has no flow-rate problem by construction. |
| MASS-02 | Added mass per satellite improves while velocity rises | 1.343 kg against A37's 1.608, at 30.54 m/s against 27.1, because A37's selected point was the large stage class and this needs only 2.18 m of stroke. Threshold unmoved at 2.0 kg; dry mass per satellite still crosses at 7.042. |
| PRECISION-01 | The precision argument finally lands on a mechanism | Charge pressure gives 0.499 % of velocity per 1 %, and it is a static measurement taken before the shot. A40 measured valve timing at 10.53 % per ms. Commanding on the charge stroke is ~21x more precise than commanding during it. |
| RATIO-01 | The expansion ratio is the binding variable, not the pressure | Velocity saturates toward a 2139 J constant-pressure ceiling, exactly A39's assumption, while gas grows linearly with chamber volume. 2 L to 4 L buys 1.0 m/s and costs 3.2 kg. |
| PRED-02 | Three predictions, three wrong, on a run where every band passed | The seal was predicted to bite: tolerance is 0.83 mbar·L/s against static seals at 10⁻⁶, wrong by four orders. Refined to friction: tolerance 83.4 N, wrong by 4x. Then the gas budget: 4.66 kg against a 12.55 budget, wrong by 2.7x. The first two were caught and corrected before declaring; the third was declared in confidence and failed. |
| HONEST-02 | And that is the pattern, stated rather than buried | Every intuition about what would bite has been wrong since A35, and every band has caught it. It is an argument for declaring bands, not for trusting the person declaring them. |
| ADR-02 | ADR-032's second falsifier retired and replaced with a narrower one | Not *"the regulator weighs more than the store"*, there is none. Now: *"a 2 L chamber cannot be filled to 50 bar inside the inter-shot window"*, which A41 did not check and A42 should ask first. |

What authorised it. P63, and A40's third named repair. No band was edited, widened or moved;
A41's eight were committed before `analysis/precharged.py` existed. All four checks pass.

---
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

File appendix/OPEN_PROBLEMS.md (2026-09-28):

# Open problems, known errors, and the fix list

Two categories: P-items are errors in the currently published paper and should be
fixed first. E-items are genuinely unsolved engineering.

> ## How to read the counts
>
> <!-- REGISTER_COUNTS:BEGIN -->
> 154 numbered entries, of which 51 are live. Every entry carries a
> `Status:` line written by `tools/register_status.py`. This block and the result JSON
> are generated from the same classifications.
>
> | Status | Count | Meaning |
> |---|---:|---|
> | `LIVE` | 51 (31 P, 20 E) | open engineering; something still has to be done |
> | `CORRECTED` | 60 | found, fixed and propagated, retained as the published record |
> | `CLOSED` | 43 | resolved, with the closer named in the entry |
> <!-- REGISTER_COUNTS:END -->
>
> Four of those moves are a classifier repair, not new engineering. `\bRESOLVED\b` matched
> inside *depth-resolved*, and the tool read its own `Status:` line back in on the next run, so a
> single wrong call re-justified itself forever. P18, P30 and P32 were sitting as `CLOSED` on the
> strength of a hyphenated adjective; P43 was sitting as `CLOSED` on the same latch. The
> conservative direction is `LIVE`, and the repair moved three entries into it.
>
> These counts were stale by four entries until 2026-08-10, under a sentence claiming they
> "cannot drift apart again". They could: `register_status.py --check` validates each entry's
> own `Status:` line, and never read this table. The claim has been removed rather than repaired,
> because the table is still hand-copied from the tool's output and a promise the checks do not
> enforce is worth less than none. Run `python3 tools/register_status.py` and compare before
> quoting these numbers anywhere.
>
> Update 2026-09-06. The current count block above is now generated and checked alongside the
> result JSON. The earlier failure and classifier history remain below it. No entry changed
> disposition in this repair.
>
> This distinction did not exist until 2026-08-06 and its absence was itself a defect: a
> reader could not separate live engineering debt from published history, so "37 defects" counted
> both. `docs/PHASE_I_CLOSURE.md` §0 named fixing it as the first act of closing Phase I.
>
> The statuses are classified from each entry's own text. A handful sit close to the boundary
> between `LIVE` and `CORRECTED`, where the defect is fixed but a consequence remains, and are
> marked `LIVE`, which is the conservative direction.

> ## FROZEN 2026-08-10, [ADR-021](docs/adr/021-freeze-the-register.md)
>
> This register is closed to new entries except in three cases. It remains authoritative and
> nothing in it has been deleted, closed or downgraded, all 81 entries stand, and the 38 live
> ones still carry their named next steps. A freeze is not a purge.
>
> A new numbered entry may be opened only for:
>
> 1. a defect in the machine, an error in the design or a model of it that changes what the
>    hardware would do;
> 2. a defect that makes a published Phase I deliverable wrong, the paper, `BASELINE.md`,
>    the portfolio. This is the P38 case and it stays numbered;
> 3. a validation band miss. `validation/README.md`'s rule is untouched: a missed band
>    produces a numbered defect, never a widened band.
>
> Everything else is fixed in place with a `CHANGELOG.md` line and no number, defects in
> `tools/`, bookkeeping drift, stale cross-references, and observations about this file.
> P39 would not be numbered under this rule. It keeps its number because the freeze is not
> retroactive and this project does not rewrite its record.
>
> Why. The discipline caught a separation figure wrong by 5.7x, a force 37 % high, a claim in
> the paper's own abstract, and P38. It also grew to ~16,000 lines of prose around ~3,200 lines of
> analysis, and began producing its own defects: of the three entries opened on 2026-08-10, one
> was in the paper and one was in the export tool's file-copying semantics. Meanwhile B-1, the
> first measured number in this project, ~₹22,000, bill of materials already written, has never
> been ordered. ADR-021 has the full argument and states what the freeze risks.
>
> The band rule is not affected, and neither is Phase II: `VOLLEY-lab`'s register is not
> frozen. Reviewed at the next baseline boundary.

Last reviewed 2026-08-10.

---

## Lethality ranking, confirmed 2026-08-10

Ordered by how likely each live entry is to be design-fatal, not by ID, date, or the
HIGH/MEDIUM/LOW severity already carried in each entry. Those severities rank *how wrong a
published number is*; this ranks *how likely the machine is not worth building*. The two orders
are different, and neither replaces the other.

Nothing below is deleted, renumbered, or reworded. This section only orders what already
exists, and the entries it points at remain the authority on their own content.

Confirmed by the author on 2026-08-10, including the two places where it disagrees with the
register's own severity labels.

### The five most likely to be design-fatal

| # | Entry | The failure it would cause | What would settle it either way |
|---|---|---|---|
| 1 | E30 | Below r = 0.99326 per element per cycle, the machine delivers less total mission value than a spring dispenser, nine of thirteen elements forfeit the remaining manifest where a spring forfeits one satellite. The product then has no reason to exist | Cycle-life test of the escapement, retention gate and sled to twelve cycles with margin, giving a measured per-element reliability. This is metal, not computation |
| 2 | E4 | Every number in the repository descends from a field model checked only analytic-against-analytic. If the measured thrust constant departs materially from 11.03 N per kA/m, the design point, the velocity, the lifetime multiplier and the comparison against a spring all move together | B-1, a gaussmeter and eight magnetised blocks, ₹22,000, method and bill of materials already written in `docs/B1_ORDER.md`. Unordered |
| 3 | E33 | The residual dipole from magnet tolerance saturates a 15 N·m·s wheel in 3.0-7.5 days with the machine idle. Combined with E31, a host that has lost attitude authority may not legally deploy, so the campaign ends before the manifest does | Measure the moment and axis of each block on receipt and compute the assembled residual, rather than assuming the Monte-Carlo tolerance distribution. The same instrument B-1 buys |
| 4 | E34 | The modelled 200 g arrest puts 18.5 kN through the structure while other satellites are stowed. The project's 25 g study ceiling is not a CubeSat qualification. If the payload-specific shock case does not close, arrest loads or geometry must change; the modelled 50 g case needs another 202 mm of run-out | A shock response spectrum and force-time history at the cassette interface, compared with a named payload's qualified levels and provider interface |
| 5 | E35 | The payload sits 20 mm from the array at 442x a magnetometer's full scale, and soft-magnetic parts leave permanently magnetised. The claim that the satellite is never modified is therefore false as built, and that claim is the product | Carry a longitudinal-separation layout into `cad/parameters.json` and recompute the field at the real payload station, or write a magnetic-cleanliness limit into a payload interface document. Computation, not test |

### Where the rest sit

Serious but not fatal, each has a known fix and the fix is affordable. P46 (K_t is
4.42 % high) moves the design point but not the architecture; P28, P36, P37, P41
and P32 are design or analysis work with no result yet suggesting the machine cannot be
built; E29 and E31 compound E33 rather than standing alone; E32 reduces to a written
inhibit.

Bounded scope rather than viability. E9, P44 and E28 narrow what the machine can
serve without threatening whether it works at all.

Bookkeeping, provenance and hygiene. P10, P14, P19, P20, P33, P35,
P38, P39, E16, E18 and E25 are records that disagree with each other or with
their sources. They matter for whether the repository can be trusted; none of them is a reason
the hardware would fail.

Not engineering. E14 and E15 are disclosure and funding.

### The disagreement this ranking has with the register's own severities

E4 carries no severity label at all and is ranked second here. P34 is labelled HIGH and
does not appear in the top five, because a magnetometer-carrying payload being excluded bounds
the market rather than the machine, and E35 may remove the constraint entirely. P45 is
labelled LOW and is genuinely low. Confirmed as written. If it is revised later, the entries themselves are unchanged and this
section is the only thing that needs editing.

---

## P: Errors found while building this repo (paper does not match its own scripts)

> STATUS (2026-07-23): P1, P4 all RESOLVED in `paper/paper.tex`. Fixes, causes and
> before/after values are logged in `CHANGELOG.md` (entries P2-01, P2-04). The items are
> kept in full below for the audit record. Two related defects found in the process were
> also fixed: the F06 conjunction figure was regenerated at the rated velocity, and a
> stale `astro.py` docstring value was corrected, both logged in `CHANGELOG.md`.

### P1. Conjunction minimum is wrong AND not a robust quantity: HIGH PRIORITY
> **Status:** `CLOSED` — resolved; see the entry for what closed it

RESOLVED 2026-07-23, see CHANGELOG.md P2-01.
The paper states a 30-day minimum satellite-to-stage approach of 45.3 km. That
figure was computed at 20.65 m/s, the superseded operating point. At the paper's
own rated velocity of 20.37 m/s, `analysis/astro.py` gives 4.6 km.

Worse, the quantity is fragile. Sweeping ejection velocity:

| Î"v (m/s) | min approach (km) |
|---|---|
| 20.00 | 37.5 |
| 20.37 (rated) | 4.6 |
| 20.50 | 56.1 |
| 20.65 (paper's value) | 45.3 |
| 21.00 | 63.4 |

This is a near-resonant beat sample, not a design property. A ±2.5 % velocity change
moves it by more than an order of magnitude.

Follow-up: `validation/A6_conjunction_cara.md` specifies the quantitative version,
probability of collision via NASA's CARA tools, which integrates over the covariance
instead of sampling one geometry. The test is whether Pc stays stable across the velocity
sweep that moves minimum distance by an order of magnitude.

> A6 ran 2026-07-31 in a reduced form and P1 stays open. Without GMAT, CARA or
> Space-Track there is no real covariance, so a 2-D Pc was computed against `astro.py`'s own
> propagator with an assumed one. The stability test came back void: at 14 to 63 km miss
> distances against a hundreds-of-metres covariance, Pc underflows double precision, and a
> spread of zeros is not a number.
>
> What the run found instead is better than what it was looking for. Pc has a maximum over
> covariance scale, a covariance wide enough to reach a 14.5 km miss is too diffuse to put
> probability inside a 5 m disc, and that maximum is 3.7e-8, some 2700x below the 1e-4
> anyone would act on, for any covariance whatsoever. So Pc is not *robust* where distance is
> fragile; it is irrelevant, bounded far below any action threshold.
>
> This does not close P1, because a bound is not a probability. It does say the paper's
> current position, the 9.9-day realignment period plus mandatory per-shot COLA, and no
> minimum-distance claim, is the right one, and is now supported rather than merely honest.

Fix: stop quoting a specific minimum distance as a safety result. Reframe around
what IS robust: the ~8.1-day phase realignment period, and the mitigation of disposing
of the host stage before the first realignment. State plainly that per-shot COLA is
mandatory because the approach geometry is sensitive to exact ejection velocity.

### P2. Peak current is stale: MEDIUM PRIORITY
> **Status:** `CLOSED` — resolved; see the entry for what closed it

RESOLVED 2026-07-23, see CHANGELOG.md P2-02.
Paper says 323 A. That belongs to the superseded 130 kA/m point. At the rated
140 kA/m, `motor_model.py` gives 392 A. Fix the paper, and check that the SiC
device derating discussion still holds at the higher current (it should, 96 V rail,
1200 V devices, but the current rating of the bridge and busbars needs restating).

### P3. Far-field stray values don't reproduce exactly: LOW PRIORITY
> **Status:** `CORRECTED` — found, fixed and propagated. Retained as the published record

> QUANTIFIED 2026-08-05 by `analysis/far_field_sensitivity.py`. P3's diagnosis was right and
> the size of it was not known. Sweeping `build_field(n_wave)` from 3 to 15 wavelengths against a
> converged reference:
>
> | Station | Deviation at the default n=7 (336 mm) | Converged |
> |---|---:|---:|
> | 10 mm | 0.64 % | 22.688 mT |
> | 20 mm | 4.36 % | 4.290 mT |
> | 50 mm | 374 % | 0.104 mT |
>
> The 10 mm value is converged and the 50 mm value is not remotely. At n=7 it is 0.49 mT
> against a converged 0.104, and it is still 16 % out at n=13. The paper's 1.0 mT corresponds to
> an array shorter than the CAD's 340 mm. No 50 mm stray figure in this project should be
> cited, including the 0.4 mT in `field_verification.json`, until the array length is set to
> the CAD value and the model converged.
>
> This needs no mesh: magpylib's Cuboid is an exact analytic solution for a uniformly magnetised
> block, so the field is already three-dimensional. What was missing was the convergence check.
RESOLVED 2026-07-23, see CHANGELOG.md P2-03.
Paper quotes 22.7 / 4.7 / 1.0 mT at 10 / 20 / 50 mm. `verify_field.py` reproduces
22.7 mT at 10 mm exactly but gives 4.3 and 0.4 mT at 20 and 50 mm. Likely sensitivity
to modelled array length (edge effects dominate the far field). The 10 mm value is the
one that sets the keep-out spec, so this is minor, but resolve it before anyone cites
the 20/50 mm numbers.

### P4. Brake fin temperature rise conflates per-shot with per-campaign: MEDIUM PRIORITY
> **Status:** `CLOSED` — resolved; see the entry for what closed it

RESOLVED 2026-07-23, see CHANGELOG.md P2-04.
The paper states the 0.86 kg copper fin sees "an adiabatic 37 K transient rise" per
shot, and later refers to "the adiabatic per-shot rises (0.3 K coil, 37 K fin)".

`analysis/sizing.py` gives 1008 J into 0.86 kg of copper = 3.0 K per shot. The 37 K
figure is the *full 12-shot campaign* total if the fin never radiated between shots
(12 x 1008 J / 331 J/K = 36.5 K).

The design is therefore *less* thermally stressed than the paper claims, but the number
as written is wrong and internally inconsistent.

Fix: state 3.0 K per shot, and 37 K as a bounding campaign-adiabatic case that
radiation between shots relieves. Same correction applies to the coil: 0.28 K per shot,
3.3 K campaign.

---

## P: CAD reconciliation and packaging (found in the 2026-07-23 Fusion 360 CAD build)

> These arose when the parametric design was taken into CAD across nine Fusion documents.
> The CAD is authoritative for geometry and fit only; `analysis/*.py` remains
> authoritative for mass and performance until FEA closes the open items. All
> geometry values below are traceable to `cad/parameters.json`. No number in
> `analysis/*.py` or `paper/paper.tex` has been changed on the strength of the CAD.

### P5. CAD sled mass contradicts the parametric assumption: RESOLVED 2026-07-29
> **Status:** `CLOSED` — resolved; see the entry for what closed it

> RESOLVED. `motor_model.M_SLED` and `sizing.M_SLED` now carry the CAD-derived 9.445 kg
> (P15), not the 4.86 kg parametric estimate. A4 ran, the drawn plate passed all three
> structural bands, and the measurement fell in the decision rule's >= 6.80 kg branch, so the
> rule resolved this rather than a judgement call. Caveat carried forward: 9.445 kg is
> the as-drawn, unpocketed geometry and A4 reports a 17x stress margin, so a rib-stiffened
> chassis would recover mass. Designing one is the open successor to this item
> (`docs/ROADMAP.md`), and it is tracked under E2 rather than here.

Original item follows for the audit trail.

> UPDATE 2026-07-28, A4 structural leg has RUN (CalculiX). The as-drawn 6 mm plate
> passes every declared band: 0.0194 mm airgap closure against a 0.025 mm per-plate budget,
> 33.7 MPa against 587 allowable, first mode 3408 Hz against >200. So there is no
> structural argument for the chassis being lighter than drawn, a lighter one has to be
> designed (rib-stiffened), not assumed. Combined with P15's CAD-derived 9.445 kg, the decision
> rule's >=6.80 kg branch stands and the machine as it exists delivers 16.53 m/s.
The first-pass Fusion sled (6 mm Ti-6Al-4V chassis, stiffness-driven by the ±0.05 mm gap
tolerance under 3.7 kN inter-array attraction, 2.69 kN since A12, no structural FEA behind it) implies a
sled mass of ~7.50 kg. `analysis/mass_properties.py` assumes 4.86 kg, which
`motor_model.py` hard-codes as `M_SLED` and which sets the headline exit velocity. Both
are estimates (one CAD-geometric, one parametric-solid) and neither is FEA-verified. Do
not change the scripts until analysis A4 closes the chassis, specified with a
pre-declared decision rule in `validation/A4_sled_structural.md` (CalculiX or
Code_Aster, both free, both read `cad/step/gen3/EMOCD_Sled_Gen3.step`). Source:
`cad/parameters.json` (sled group, `PROVISIONAL_PENDING_FEA`).

### P6. Payload seating / orientation: RESOLVED (by CAD, 2026-07-23)
> **Status:** `CLOSED` — resolved; see the entry for what closed it

Resolved via the rail interface: the 3U payload now models the four CubeSat Design
Specification corner rails (8.5 mm, `cad/parameters.json` `payload_3u`), which fix seating
and orientation against the sled cradle. No further action.

### P7. Brake sits past the release point: geometry / ConOps, CLOSED 2026-08-10
> **Status:** `CLOSED` — resolved; see the entry for what closed it

The eddy brake occupies x = 1530-1740 mm, beyond the 1500 mm satellite release
point, on an 1800 mm longeron. The sled runs on into the brake after the payload departs
consistent with the fire-then-arrest ConOps, but it forces the track and enclosure to
extend past release, which drives the envelope length (see P9). Source:
`cad/parameters.json` (brake, track).

Closed 2026-08-10 by the Gen4 layout, geometrically. `docs/GEN4_STATUS.md` moves release to
s = 1200 mm on a 900 mm acceleration stroke and puts brake-fin entry at s = 1222 mm, so
the release station sits 22 mm before the fin reaches x = 1530 mm. The fin then occupies the
brake interval over 330 mm of sled travel, s = 1222 to 1552 mm. The release-into-brake overlap
is gone, and it is gone without adding track length. Recorded against A16, which computed
the Gen4 finite-stator thrust on this layout, and P32.

The second half of this entry was never P7's to carry. "It forces the track and enclosure to
extend past release, which drives the envelope length" is true and still true, Gen4 keeps the
track at 1800 mm and the brake at 1530-1740 mm. That is the envelope problem, and the envelope
problem is P9, which is a kill-criterion item with an owner decision attached. P7 asked whether
the *overlap* was a defect. It was, Gen4 resolves it, and nothing is gained by keeping a second
entry pointed at P9's problem.

> What this close is worth, stated plainly. Gen4 is a CAD configuration record and has not
> been exported into this repository, `GEN4_STATUS.md` says so in its own first paragraph, and
> the committed STEP, analyses and baseline remain the Gen3 record. So this closes a geometry
> question against a geometry that is not yet committed. It is closed because the layout
> resolves it and the layout is recorded, not because anything was measured. If the Gen4 export
> lands with a different release station, this reopens.

### P8. Exit velocity provisionally 17.88 m/s pending sled structural FEA: RESOLVED 2026-07-29
> **Status:** `CLOSED` — resolved; see the entry for what closed it

> RESOLVED, and not at 17.88 m/s. That figure came from the 7.50 kg CAD estimate. The
> CAD-derived mass is 9.445 kg, so the rated velocity is 16.537 m/s at 10.7 g, now
> propagated into `analysis/`, `paper/paper.tex`, the figures and every front page. The
> machine is no longer acceleration-limited: at 10.7 g against a 25 g cap it is
> thrust-and-mass limited, which changes what recovering velocity means (mass or current,
> not stroke).

Original item follows for the audit trail.

If the CAD sled mass (P5) holds, exit velocity falls from the script's 20.37 m/s to a
provisional ~17.88 m/s (with acceleration ~12.5 g, efficiency ~24 %, recoil
~71.5 N·s, lifetime multiplier x1.68, all CAD-corrected and provisional). These values
are NOT propagated into `analysis/*.py` or `paper/paper.tex`; the scripts stay
authoritative until analysis A4 locks the sled mass (`validation/A4_sled_structural.md`,
which fixes in advance which of the two estimates wins at which mass). Do not hard-swap
20.37 to 17.88 anywhere. Source: 2026-07-23 CAD Master Plan; see README headline note.
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

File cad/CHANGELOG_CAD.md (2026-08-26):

# CHANGELOG_CAD: EMOCD_figs
VOLLEY, an electromagnetic orbital CubeSat deployer
CAD Generation History, Design Rationale, and Audit Record

Author: Adityavardhan Mishra, Symbiosis Institute of Technology, Pune
PRN: 23070125054
Last updated: 2026-08-03

Read alongside:
- `EMOCD-main/CHANGELOG.md`, analysis and paper change history
- `EMOCD-main/OPEN_PROBLEMS.md`, full defect and open-problem list
- `EMOCD-main/PROVENANCE.md`, what stands behind each claim
- `EMOCD-main/cad/parameters.json`, single source of truth for all dimensions

Governing rule: `cad/parameters.json` is the single source of truth for
all dimensions. Fusion 360 is authoritative for geometry and fit only.
`analysis/*.py` is authoritative for mass and performance until FEA closes
the open items. No number in the scripts or the paper is changed on the
strength of CAD geometry alone. Nothing is ever deleted from this file,
superseded content is marked SUPERSEDED in place.

---

## 2026-08-10: GEN4 RENDER SET PUBLISHED, GEN4 STILL NOT EXPORTED

Seven Gen4 shots replace the Gen3 render set on every public surface. The Gen3 firing-sequence
frames were withdrawn under P43: two of them showed the payload departing *through* the ESPA
mounting flange and drew the CubeSat as a wheeled road vehicle from a sample-asset library.

| Published | Superseded |
|---|---|
| `hero_open.png` | `interior_open.png` |
| `espa_interface.png` | `exterior_aft_mounting.png` |
| `envelope_closed.png` | `exterior_closed.png` |
| `sled_detail.png` | `seq2_midstroke.png` |
| `brake.png` | `seq4_braking.png` |
| `track_stator.png`, `magazine_feed.png` | new shots |
|, | `seq1_stowed.png`, `seq3_release.png` withdrawn without replacement |

`exploded_view.png` is the only Gen3 render retained, because Gen4 has no equivalent, and it is
labelled Gen3 wherever it appears.
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

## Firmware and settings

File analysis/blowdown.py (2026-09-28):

"""
VOLLEY | The blowdown transient: does the gas arrive in time, and can velocity be commanded?

WHY THIS EXISTS
---------------
P60, and A39's own closing sentence: gas removes a mass problem and introduces a fluid-system
problem, and A39 sized the first and not the second. It chose gas on a quasi-static argument
-- swept volume times working pressure equals the energy needed -- and never asked whether the
gas can ARRIVE in time. Filling 0.428 litres in a 133 ms stroke is roughly 3 L/s.

Nothing about LegacyStudy's geometry can be drawn until this closes. The bore, the reservoir and the
valve are the first three dimensions in cad/parameters.json.

AND A SECOND QUESTION A39 COULD NOT ASK
---------------------------------------
A falling reservoir means every shot is different, against a project whose whole proposition
is a velocity commanded per satellite. The candidate mechanism is VALVE CUT-OFF: open, close
at a commanded time, coast the rest of the stroke. Velocity becomes a function of timing
rather than of pressure -- a digital quantity, and the same trick the linear motor played
with current.

Bands declared in validation/A40_blowdown_transient.md at 0d05ea2, BEFORE this file existed.

Provenance: model output. Isentropic choked flow, ideal gas, adiabatic reservoir and cylinder.
No line losses, no wall heat transfer, no seal friction, no valve dynamics beyond the declared
ramp. Every one of those omissions makes this optimistic.
"""
import json
import math
import os

RESULTS = os.path.join(os.path.dirname(os.path.abspath(__file__)), 'results')

# Gas: nitrogen
GAMMA, R_GAS, T0 = 1.4, 296.8, 300.0
CD = 0.8                              # orifice discharge coefficient
CRIT = (2.0 / (GAMMA + 1.0)) ** (GAMMA / (GAMMA - 1.0))     # 0.528

# Geometry, from A39
BORE = 0.015805366135494582
AREA = math.pi * (BORE / 2.0) ** 2
STROKE = 2.18
P_STORE, P_WORK = 200e5, 50e5
RESERVOIR = 1.7108640e-3              # m3
M_PAY = 4.0
G = 9.81
G_CAP = 25.0
DEAD_VOLUME = AREA * 0.010            # 10 mm of cylinder behind the piston at rest
P_AMBIENT = 0.0                       # vacuum
VALVE_RAMP_S = 2e-3                   # orifice opens linearly over 2 ms


def mdot(p_up, rho_up, p_dn, area):
    """Isentropic mass flow through `area` from (p_up, rho_up) to p_dn. Choked below CRIT."""
    if area <= 0.0 or p_up <= p_dn:
        return 0.0
    ratio = max(p_dn / p_up, 1e-12)
    if ratio <= CRIT:
        flux = math.sqrt(GAMMA * p_up * rho_up) * \
            (2.0 / (GAMMA + 1.0)) ** ((GAMMA + 1.0) / (2.0 * (GAMMA - 1.0)))
    else:
        flux = math.sqrt(2.0 * GAMMA / (GAMMA - 1.0) * p_up * rho_up
                         * (ratio ** (2.0 / GAMMA) - ratio ** ((GAMMA + 1.0) / GAMMA)))
    return CD * area * flux


def shot(orifice_m2, p_res0, cutoff_s=None, dt=2e-7, v_cap=None):
    """One shot. Returns exit state, peak acceleration and gas consumed.

    Reservoir expands adiabatically; the cylinder is filled adiabatically while the piston
    does work on the payload. `cutoff_s` closes the orifice at that time -- the payload then
    coasts on the gas already admitted, which keeps pushing as it expands.
    """
    rho_res = p_res0 / (R_GAS * T0)
    m_res = rho_res * RESERVOIR
    p_res = p_res0

    m_cyl, x, v, t = 0.0, 0.0, 0.0, 0.0
    p_cyl = P_AMBIENT
    a_peak = 0.0
    while x < STROKE and t < 2.0:
        vol = DEAD_VOLUME + AREA * x
        open_frac = 0.0 if (cutoff_s is not None and t >= cutoff_s) \
            else min(1.0, t / VALVE_RAMP_S)
        flow = mdot(p_res, m_res / RESERVOIR, p_cyl, orifice_m2 * open_frac)

        # reservoir: adiabatic expansion of the gas that stays behind
        m_res_new = m_res - flow * dt
        if m_res_new <= 0.0:
            m_res_new, flow = 0.0, m_res / dt
        p_res = p_res0 * (m_res_new / (rho_res * RESERVOIR)) ** GAMMA
        m_res = m_res_new

        # cylinder: energy added by inflow, minus work done on the piston
        m_cyl += flow * dt
        if m_cyl <= 0.0:
            p_cyl = P_AMBIENT
        else:
            # adiabatic with mass addition at reservoir stagnation enthalpy
            p_cyl = p_cyl + (GAMMA * R_GAS * T0 * flow / vol
                             - GAMMA * p_cyl * AREA * v / vol) * dt
            p_cyl = max(p_cyl, 0.0)

        a = p_cyl * AREA / M_PAY
        a_peak = max(a_peak, a)
        v += a * dt
        x += v * dt
        t += dt
        if v_cap and v > v_cap:
            break
    return dict(v_exit=v, t_s=t, x_m=x, a_peak_g=a_peak / G,
                gas_used_kg=rho_res * RESERVOIR - m_res,
                p_res_end=p_res)


def bisect_orifice(target_g=G_CAP, lo=1e-7, hi=1e-4):
    """Largest orifice whose peak acceleration stays inside the qualification cap."""
    for _ in range(60):
        mid = 0.5 * (lo + hi)
        if shot(mid, P_STORE)['a_peak_g'] <= target_g:
            lo = mid
        else:
            hi = mid
    return lo


def main():
    # band 1: open the orifice wide and the transient must contain the quasi-static answer
    quasi = shot(100e-6, P_STORE)

    orifice = bisect_orifice()
    d_mm = 2e3 * math.sqrt(orifice / math.pi)
    nominal = shot(orifice, P_STORE)

    print(f"orifice sized on the {G_CAP:.0f} g cap: {orifice*1e6:.3f} mm2, "
          f"{d_mm:.2f} mm diameter")
    print(f"  shot 1   v {nominal['v_exit']:6.2f} m/s   peak {nominal['a_peak_g']:5.2f} g   "
          f"t {nominal['t_s']*1e3:6.1f} ms   gas {nominal['gas_used_kg']*1e3:6.2f} g")

    # band 5: twelve shots in sequence off one bottle
    p, seq = P_STORE, []
    for i in range(12):
        s = shot(orifice, p)
        seq.append(dict(shot=i + 1, p_res_bar=p / 1e5, v_exit=s['v_exit'],
                        a_peak_g=s['a_peak_g'], gas_used_g=s['gas_used_kg'] * 1e3))
        p = s['p_res_end']
    print(f"\n{'shot':>4s} {'p_res bar':>10s} {'v m/s':>8s} {'peak g':>7s} {'gas g':>7s}")
    for r in (seq[0], seq[5], seq[10], seq[11]):
        print(f"{r['shot']:4d} {r['p_res_bar']:10.1f} {r['v_exit']:8.2f} "
              f"{r['a_peak_g']:7.2f} {r['gas_used_g']:7.2f}")
    droop = seq[-1]['v_exit'] / seq[0]['v_exit']

    # band 6: is velocity commandable by valve cut-off?
    print("\ncommanding velocity by valve cut-off:")
    cut = []
    for ms in (2, 3, 4, 5, 6, 8, 10, 15, 20, 40, None):
        s = shot(orifice, P_STORE, cutoff_s=None if ms is None else ms * 1e-3)
        cut.append(dict(cutoff_ms=ms, v_exit=s['v_exit'], a_peak_g=s['a_peak_g']))
        print(f"  cut at {str(ms)+' ms' if ms else 'never ':>8s}  v {s['v_exit']:6.2f} m/s")
    finite = [c for c in cut if c['cutoff_ms']]
    monotonic = all(finite[i]['v_exit'] <= finite[i + 1]['v_exit'] + 1e-9
                    for i in range(len(finite) - 1))
    span_lo, span_hi = finite[0]['v_exit'], finite[-1]['v_exit']

    # band 7: sensitivity to a 1 ms timing error at a mid-range cut-off
    base_ms = 6
    v0 = shot(orifice, P_STORE, cutoff_s=base_ms * 1e-3)['v_exit']
    vp = shot(orifice, P_STORE, cutoff_s=(base_ms + 1) * 1e-3)['v_exit']
    vm = shot(orifice, P_STORE, cutoff_s=(base_ms - 1) * 1e-3)['v_exit']
    timing_pct = max(abs(vp - v0), abs(vm - v0)) / v0 * 100.0
    print(f"\n  +/-1 ms at a {base_ms} ms cut-off ({v0:.2f} m/s): "
          f"{timing_pct:.2f} % velocity error")

    a39_swept_kg = (P_WORK / (R_GAS * T0)) * AREA * STROKE
    bands = [
        ('1', 'wide orifice reproduces A39 32.7 m/s within 2 %',
         f"{quasi['v_exit']:.2f} m/s", abs(quasi['v_exit'] - 32.7) / 32.7 <= 0.02),
        ('2', f'peak acceleration <= {G_CAP:.0f} g',
         f"{nominal['a_peak_g']:.2f} g", nominal['a_peak_g'] <= G_CAP + 1e-6),
        ('3', 'shot 1 exit velocity >= 30 m/s',
         f"{seq[0]['v_exit']:.2f} m/s", seq[0]['v_exit'] >= 30.0),
        ('4', 'orifice diameter <= 10 mm', f"{d_mm:.2f} mm", d_mm <= 10.0),
        ('5', 'shot 12 reaches >= 95 % of shot 1',
         f"{droop*100:.1f} % ({seq[-1]['v_exit']:.2f} against {seq[0]['v_exit']:.2f} m/s)",
         droop >= 0.95),
        ('6', 'cut-off spans 20 -> 30 m/s monotonically',
         f"{span_lo:.1f} -> {span_hi:.1f} m/s, monotonic {monotonic}",
         monotonic and span_lo <= 20.0 and span_hi >= 30.0),
        ('7', '+/-1 ms timing error gives <= 1 % velocity error',
         f"{timing_pct:.2f} %", timing_pct <= 1.0),
        ('8', "gas per shot within 20 % of A39's swept-volume figure",
         f"{nominal['gas_used_kg']*1e3:.2f} g against {a39_swept_kg*1e3:.2f} g",
         abs(nominal['gas_used_kg'] - a39_swept_kg) / a39_swept_kg <= 0.20),
    ]
    print("\nbands:")
    for n, name, detail, ok in bands:
        print(f"  band {n}: {'PASS' if ok else 'FAIL'}  {name}\n            {detail}")

    out = dict(analysis='A40', bands_declared_commit='0d05ea2',
               note='isentropic choked flow, ideal gas, adiabatic. No line losses, wall heat '
                    'transfer, seal friction or valve dynamics beyond a 2 ms ramp; every '
                    'omission makes this optimistic. Designs no valve, seal or manifold and '
                    'does not check A34 release residual.',
               bore_m=BORE, area_m2=AREA, stroke_m=STROKE, reservoir_m3=RESERVOIR,
               p_store_Pa=P_STORE, orifice_m2=orifice, orifice_mm=d_mm,
               quasi_static=quasi, nominal=nominal, sequence=seq,
               droop_shot12_over_shot1=droop, cutoff_sweep=cut,
               timing_sensitivity_pct_per_ms=timing_pct,
               bands=[dict(band=n, name=nm, detail=d, pass_=ok)
                      for n, nm, d, ok in bands])
    os.makedirs(RESULTS, exist_ok=True)
    path = os.path.join(RESULTS, 'blowdown.json')
    with open(path, 'w', encoding='utf-8') as fh:
        json.dump(out, fh, indent=2, default=float)
        fh.write('\n')
    print(f"\nwrote {path}")


if __name__ == '__main__':
    main()

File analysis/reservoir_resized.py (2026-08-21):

"""A56: the reservoir at the charge pressure ADR-034 adopted. P82.

Bands declared in validation/A56_reservoir_resized.md at HEAD~1, BEFORE this file existed.

WHY THIS EXISTS
---------------
ADR-034 dropped the charge pressure 50 -> 22.7258 bar and cut gas per shot by 54.55 %. The
reservoir did not move: parameters.json still carries 9.55 L, which A43 sized around 50 bar
refills. And the store mass ADR-034 quotes is A49's gas-ratio SCALING of A43's 5.38 kg, not a
sized store -- the ADR says so in its own falsifier 2.

WHAT A43 ESTABLISHED, AND THE QUESTION IT LEAVES
------------------------------------------------
A43's finding was not a volume. It was that the bottle does not warm back up: conduction through
stagnant nitrogen gives 17460 s against a 1200 s cadence, so the NO-RELAXATION figure is the
physically right end rather than merely the conservative one.

That argument is about the gas, not the pressure. But the time constant scales with the
reservoir's own size and the reservoir is about to get smaller, and a smaller bottle relaxes
faster. Whether it relaxes fast enough is band 4 and it is not obvious in advance.

THE SEARCH FLOOR WAS BINDING
----------------------------
reservoir_thermal.required() searches upward from 4.0 L, set when the answer was around 9 L. At
the new charge pressure it returns 4.0 L -- the floor itself. A search cannot see below its own
starting point, so this run lowers the floor and reports that it was binding (band 2).

Everything else is A43's model, imported rather than restated.

Run:  python3 analysis/reservoir_resized.py
"""
import json
import math
import os

import fill_window as fw
import reservoir_thermal as rt

RESULTS = os.path.join(os.path.dirname(os.path.abspath(__file__)), 'results')

FLOOR_L = 0.5e-3                  # A43's floor was 4.0e-3 and is binding at the new point
STEP_L = 0.01e-3                  # finer than A43's 0.05 L, since the answer is smaller
A43_NO_RELAX_L = 9.55             # the figure in parameters.json, from A43
P_SWEEP_BAR = (15.0, 20.0, 22.7258, 25.0, 30.0, 40.0, 50.0)
H_NO_RELAX = 0.0                  # A43's no-relaxation end: the one parameters.json carries
CHAMBER_KG, HARDWARE_KG = fw.CHAMBER_KG, fw.HARDWARE_KG
ADDED_BASE_KG = fw.ADDED_BASE_KG
PER_SAT_TUBE_KG = 1.1404          # A49's tube, carried so the per-satellite figure is comparable


def required(orifice_m2, h, p_charge, floor=FLOOR_L, step=STEP_L, vmax=rt.V_SEARCH_MAX):
    """A43's search, with the charge pressure explicit and a floor that is not binding."""
    old = fw.P_CHARGE
    fw.P_CHARGE = p_charge
    try:
        v = floor
        while v < vmax:
            _, failed, _ = rt.sequence(v, orifice_m2, h)
            if failed is None:
                return v
            v += step
        return None
    finally:
        fw.P_CHARGE = old


def at_pressure(p_charge, orifice_m2, h=H_NO_RELAX):
    """Required reservoir, the sequence it runs, and what the store then weighs."""
    v_res = required(orifice_m2, h, p_charge)
    if v_res is None:
        return None
    old = fw.P_CHARGE
    fw.P_CHARGE = p_charge
    try:
        seq, failed, t_min = rt.sequence(v_res, orifice_m2, h)
    finally:
        fw.P_CHARGE = old
    m_res = fw.P_STORE * v_res / (fw.R_GAS * fw.T0)
    vessel = fw.P_STORE * v_res / (fw.PV_OVER_W * 9.81)
    gas = v_res * fw.RHO_STORE
    store = CHAMBER_KG + vessel + gas + HARDWARE_KG
    tau_s = rt.tau(m_res, v_res, rt.conduction_h(v_res))
    return dict(p_charge_bar=p_charge / 1e5, reservoir_l=v_res * 1e3,
                vessel_kg=vessel, gas_kg=gas, chamber_kg=CHAMBER_KG,
                hardware_kg=HARDWARE_KG, store_kg=store,
                per_satellite_kg=(ADDED_BASE_KG + store + PER_SAT_TUBE_KG) / fw.N_MANIFEST,
                conduction_tau_s=tau_s, tau_over_cadence=tau_s / fw.CADENCE_S,
                t_min_K=t_min, last_fill_s=seq[-1]['fill_s'],
                shots=len(seq), failed=failed)


def main():
    orifice = math.pi * (1.0 / 2e3) ** 2          # A42's 1 mm orifice
    print(f"A56 reservoir resized. A43's floor was {4.0:.1f} L; this run searches from "
          f"{FLOOR_L*1e3:.2f} L in {STEP_L*1e3:.2f} L steps\n")

    a43 = at_pressure(50e5, orifice)
    now = at_pressure(fw.P_CHARGE, orifice)
    floor_a43 = required(orifice, H_NO_RELAX, fw.P_CHARGE, floor=4.0e-3, step=0.05e-3)

    print(f"{'':>26}{'A43, 50 bar':>14}{'adopted':>14}")
    for lab, key, fmt in (('reservoir L', 'reservoir_l', '14.3f'),
                          ('vessel kg', 'vessel_kg', '14.4f'),
                          ('gas kg', 'gas_kg', '14.4f'),
                          ('store kg', 'store_kg', '14.4f'),
                          ('per satellite kg', 'per_satellite_kg', '14.4f'),
                          ('conduction tau s', 'conduction_tau_s', '14.0f'),
                          ('tau / cadence', 'tau_over_cadence', '14.2f'),
                          ('min reservoir T K', 't_min_K', '14.1f'),
                          ('last fill s', 'last_fill_s', '14.3f')):
        print(f"  {lab:>24}{format(a43[key], fmt)}{format(now[key], fmt)}")
    print(f"\n  A43's 4.0 L floor at the adopted pressure returns "
          f"{floor_a43*1e3 if floor_a43 else float('nan'):.2f} L -- "
          f"{'BINDING' if floor_a43 and abs(floor_a43 - 4.0e-3) < 1e-9 else 'not binding'}")

    print(f"\nband 9, against charge pressure:")
    print(f"  {'bar':>10}{'reservoir L':>13}{'store kg':>10}{'per sat kg':>12}"
          f"{'tau/cadence':>13}{'min T K':>9}")
    sweep = []
    for pb in P_SWEEP_BAR:
        r = at_pressure(pb * 1e5, orifice)
        sweep.append(r)
        print(f"  {pb:10.4f}{r['reservoir_l']:13.3f}{r['store_kg']:10.4f}"
              f"{r['per_satellite_kg']:12.4f}{r['tau_over_cadence']:13.2f}{r['t_min_K']:9.1f}")
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

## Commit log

2026-07-29 Generated from EMOCD flagship c927df9
    Thesis companion: the engineering record as submitted, including the decision
    records under docs/adr and all three CAD generations.
    This repository is output, not source. It is produced by tools/export_companion.py
    in the flagship and is never hand-edited -- any edit here is destroyed on the next
    regeneration. Fix mistakes in the flagship.
    The university/ directory is the exception: the exporter never touches it, so
    submission-specific material can live there without being overwritten.
    [EMOCD_Assembly_Gen1.step, EMOCD_Assembly_Gen2.step, EMOCD_Assembly_Gen3.step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]
2026-07-30 Regenerate from VOLLEY flagship cef4052
    [motor_results.json]
2026-07-31 Regenerate from VOLLEY flagship 56d7ea4
    [motor_results.json]
2026-08-05 Regenerate from VOLLEY flagship 871abe6
    [motor_results.json]
2026-08-10 Regenerate from flagship 0d3391a
    Replaces the render set withdrawn under P43, and adds the generated dimension and BOM
    tables with the CAD brief that resolves the conflicts between them.
2026-08-10 Regenerate from flagship fd1ad74
    [VOLLEY_Brake_Gen5.step, VOLLEY_Brake_Gen5.stl, VOLLEY_Enclosure_Gen5.step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]
2026-08-14 Follow the consistency sweep, and stop claiming nothing here is authored
    The main record found eight analysis scripts still running at the superseded
    16.388 m/s operating point, and one mass constant eight kilograms light. This
    picks up the corrected scripts, results and appendix.
    The manuscript, which is authored here, carried three figures that moved with
    them: recoil per shot to 64.1 N.s, the lifetime-extension ratio against the
    fastest published spring to 7.3, and the raw velocity ratio to 6.4. The
    shortened-track cost is recomputed the same way the sentence derives it.
    Rebuilt at fifteen pages with no undefined references.
    The provenance banner said every file here is generated and no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
    [motor_results.json]
2026-08-14 The thesis manuscript had forked from the conference manuscript and was two baselines behind
    They share every section heading, every figure path and 414 of 447 lines. All
    33 differences were superseded numbers: thrust constant 11.03 against 10.54,
    exit velocity 16.4 against 16.0, 10.5 g against 10.1, 2.85 kJ against 2.78,
    240 mm of regeneration stator against 39, dry mass 76.5 against 84.5,
    efficiency 21.0 against 18.8 per cent, and deployer mass per 3U satellite 6.38
    against 7.04. The depth-averaging sentence was absent entirely.
    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
2026-08-14 Pick up ADR-032, and say which generation the manuscript describes
    The main repository replaced its design target on 2026-08-14: the payload
    accelerated directly by cold gas along a rail a spent upper stage provides. The
    manuscript still describes Gen5, which is deliberate, and the README now says
    so and says why.
    Nothing in Gen6 is measured, its fluid system is unsized, its cradle mechanism
    does not exist and no launch provider has agreed to lend a stage.
    The appendix picks up the five runs behind it, including the new ADR-032 and
    the vault's record of the nine entries whose subject it deletes.
2026-08-14 Pick up the pictograph removal
    Tick and cross marks in the CAD changelog become OK and FAIL, which is what
    they meant. Decorative emoji are removed from the prose. Arrows are kept as
    typographic notation.
2026-08-15 Pick up A40 and P63: the fixed-orifice gas architecture fails
    [blowdown.py]
2026-08-15 Pick up Gen6's generated CAD and the artifact-guard repair
    [VOLLEY_Carriage_Gen6.step, VOLLEY_Carriage_Gen6.stl, VOLLEY_Chamber_Gen6.step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]
2026-08-19 Pick up the restructured front page and the ADR-034 design point
    Regenerated from the flagship. Carries ADR-034 -- the stroke becomes
    the host stage's whole 8.0 m at 22.73 bar, same exit velocity at 45.5 %
    of the acceleration and 45.5 % of the gas -- along with A49 through
    A53, the P78 friction finding, and the new register entries P80 to P84.
    The README follows the flagship's reorder: pitch and routing first,
    then what it is, how a shot works, the numbers with a column per
    generation, the comparison against a spring, the evidence, and what is
    wrong with it. Status banners that used to sit above the description
    are now dated rows in one corrections table.
    These files are output. Edit the f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
    [VOLLEY_Brake_Gen5.step, VOLLEY_Carriage_Gen6.step, VOLLEY_Chamber_Gen6.step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]
2026-08-21 P93: system mass at 126.6 kg, family table regenerated, CFD figures in the manuscript
2026-08-21 Lead with the work: field, flow, exploded assembly and the constraint ledger
2026-08-21 Regenerate the reproducibility payload, and sync the manuscript to the paper repository
    Section V argues from the current rollup and states the comparator it loses;
    Section V-C prices phase against release timing; the limitations section no
    longer says the depth-resolved thrust constant is unapplied; and the energy
    chain reports the 39 mm regenerative section. Two orphaned figures are placed
    and the wide ones span both columns.
    [VOLLEY_Reservoir_Gen6.step, VOLLEY_Reservoir_Gen6.stl, VOLLEY_Trim_Stator_Gen6.step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]
2026-08-21 Sync the manuscript and regenerate the payload
    The acceleration-ceiling correction, the spring wording and the release-timing
    statement, matching VOLLEY-paper.
2026-08-21 Landing page: analysed baseline, 18-page build, formatted not submitted
2026-08-21 Regenerate the landing page from the corrected generator
2026-08-22 Regenerate the reproducibility payload: A57 correction
    [attitude_budget.py]
2026-08-22 Regenerate the reproducibility payload: A68, A69, A70 and the mission-architecture correction
    [contact_laws.py]
2026-08-22 Regenerate the reproducibility payload: the P110 and P111 corrections
    [contact_laws.py]
2026-08-22 Regenerate the reproducibility payload: the corrected A70 result
    [contact_laws.py]
2026-08-28 Sync the payload with flagship bc84ed6: P116, the mission-case executability correction
2026-08-30 A66 and ADR-037, generated from the flagship at e85ffbd
    The tube-shielding run, its result and the acceptance-band correction behind it. Adds
    requirements-dev.txt, which requirements.txt has been naming without shipping.
2026-09-06 Refresh BSX evidence exports and correct the authored print pack
2026-09-16 Stage one-shot Gen6 reference evidence synchronization
2026-09-28 Correct thesis status and historical evidence language (#4)
    [VOLLEY_Carriage_HistoricalStudy.step, VOLLEY_Carriage_HistoricalStudy.stl, VOLLEY_Chamber_HistoricalStudy.step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]
2026-10-09 Frame final review around completed Gen5 thesis findings
2026-10-09 Align thesis CAD provenance and rebuild final review downloads
2026-10-09 Publish Gen5 final-year report, review presentation, and native CAD evidence
    [Gen5_Review.FCStd, VOLLEY_Brake_FreeCAD_Gen5.step, VOLLEY_Enclosure_FreeCAD_Gen5.step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]
2026-10-09 Publish prioritized IEEE, CAD and simulation remaining-work matrix
2026-10-09 Publish revised Gen5 thesis, 26-slide review and independent evidence pack
    [Feeder_Candidate_R1.FCStd, VOLLEY_Feeder_Assembly_FreeCAD_R1.step, VOLLEY_Feeder_Assembly_R1.step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]
2026-10-09 Tighten IEEE evidence wording and rebuild manuscript PDFs
2026-10-10 Synchronize thesis review with mass and prototype requirements
2026-10-10 Clarify Gen6 prototype scope in thesis front page
2026-10-10 Synchronize review PDFs and deck with source-power finding
2026-10-12 Clarify current Gen6 supplement order
2026-10-12 Publish standalone Gen6 Go 2 CAD and analysis supplement
2026-10-12 Synchronize Go 3 presenter and panel materials
2026-10-12 Correct unrun ground-test claim in thesis manuscript
2026-10-12 Reconcile Gen5 report and review pack with Gen6 CAD study
2026-10-19 Require Git-tracked evidence and exclude uncontrolled CAD backups
2026-10-19 Reject native CAD backup artifacts at the file gate
2026-10-21 Capture FM06 geometry, current receiver fixtures and rejected contact model
2026-10-21 Synchronize current feeder evidence across academic and public review surfaces
2026-10-21 Verify feeder contact representation with native calibration and captured refinement cases
2026-10-22 Add common-boundary feeder CAD and verified computational study findings
2026-10-26 Refresh reviewer-facing CAD views with preserved academic sources
2026-10-26 Publish versioned ED2 academic report and presentation with matched chassis cross-check
2026-10-27 Present engineering results and remove private workflow material

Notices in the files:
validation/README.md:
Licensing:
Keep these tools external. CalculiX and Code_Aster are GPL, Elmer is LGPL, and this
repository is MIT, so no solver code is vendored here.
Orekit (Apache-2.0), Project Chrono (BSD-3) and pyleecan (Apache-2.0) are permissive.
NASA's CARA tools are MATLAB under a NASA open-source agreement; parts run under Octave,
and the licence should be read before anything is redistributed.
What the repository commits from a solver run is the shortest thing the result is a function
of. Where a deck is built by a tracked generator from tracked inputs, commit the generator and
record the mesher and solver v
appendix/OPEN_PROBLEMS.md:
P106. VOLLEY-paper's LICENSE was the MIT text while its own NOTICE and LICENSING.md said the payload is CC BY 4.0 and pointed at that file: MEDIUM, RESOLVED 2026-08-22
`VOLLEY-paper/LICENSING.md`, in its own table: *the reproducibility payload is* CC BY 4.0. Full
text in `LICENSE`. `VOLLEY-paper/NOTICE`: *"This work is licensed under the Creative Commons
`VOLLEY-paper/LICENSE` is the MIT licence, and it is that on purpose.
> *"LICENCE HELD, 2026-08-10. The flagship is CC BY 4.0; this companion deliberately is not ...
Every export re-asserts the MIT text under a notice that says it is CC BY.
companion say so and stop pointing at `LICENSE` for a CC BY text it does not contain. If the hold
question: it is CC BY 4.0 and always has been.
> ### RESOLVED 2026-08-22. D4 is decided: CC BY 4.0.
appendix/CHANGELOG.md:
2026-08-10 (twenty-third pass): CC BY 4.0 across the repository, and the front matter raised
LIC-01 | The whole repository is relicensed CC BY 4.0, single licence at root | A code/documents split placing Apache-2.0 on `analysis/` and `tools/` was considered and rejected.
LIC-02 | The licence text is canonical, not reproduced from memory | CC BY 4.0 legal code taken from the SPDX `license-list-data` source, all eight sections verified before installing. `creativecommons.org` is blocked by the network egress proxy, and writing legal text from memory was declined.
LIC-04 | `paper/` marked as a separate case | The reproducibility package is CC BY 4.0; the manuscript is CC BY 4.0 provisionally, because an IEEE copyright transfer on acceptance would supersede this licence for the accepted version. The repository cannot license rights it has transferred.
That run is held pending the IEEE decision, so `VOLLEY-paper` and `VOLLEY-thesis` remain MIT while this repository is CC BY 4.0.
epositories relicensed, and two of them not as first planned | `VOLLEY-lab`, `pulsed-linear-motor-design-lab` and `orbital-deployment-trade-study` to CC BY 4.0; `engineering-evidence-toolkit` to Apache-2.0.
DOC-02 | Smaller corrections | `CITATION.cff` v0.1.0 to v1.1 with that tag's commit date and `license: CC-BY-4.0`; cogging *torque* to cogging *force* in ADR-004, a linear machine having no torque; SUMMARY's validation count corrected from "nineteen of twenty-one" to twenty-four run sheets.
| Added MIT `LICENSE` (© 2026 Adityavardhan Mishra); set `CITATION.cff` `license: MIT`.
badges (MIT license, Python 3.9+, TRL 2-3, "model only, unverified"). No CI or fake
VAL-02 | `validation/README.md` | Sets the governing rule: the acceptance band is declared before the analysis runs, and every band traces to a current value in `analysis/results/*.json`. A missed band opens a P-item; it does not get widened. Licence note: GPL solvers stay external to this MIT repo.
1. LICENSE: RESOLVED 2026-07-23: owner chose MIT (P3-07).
